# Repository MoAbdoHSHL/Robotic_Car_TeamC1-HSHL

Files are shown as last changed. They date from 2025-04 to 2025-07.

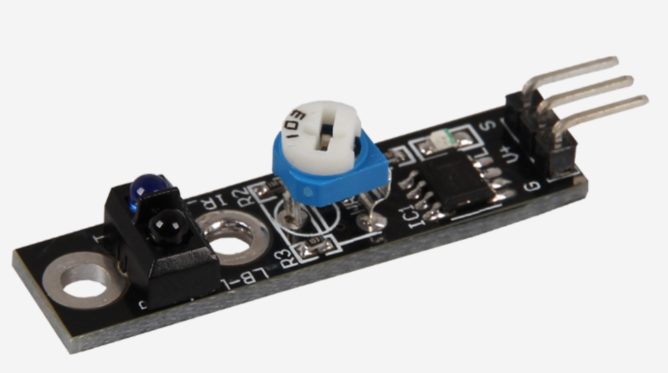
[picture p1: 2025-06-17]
Task-4/Components/IR Sensor.png

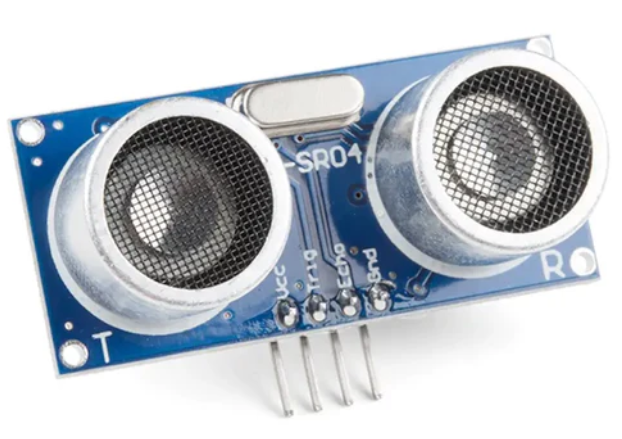
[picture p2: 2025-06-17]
Task-4/Components/Ultrasonic Sensor.png

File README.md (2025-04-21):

# Arduino Autonomous Vehicle 🚗🤖

Front_View_Car

## 🎯 Project Goal

Develop an autonomous vehicle capable of navigating a track **without human control**, using:

- **Line detection** for navigation
- **Obstacle detection and avoidance**
- **Color-based object identification**
   Ex: (to decide route or remove obstacles)
- **Speed optimization** for smooth operation
- **Multiple routing scenarios**:
  - Oval track
  - Figure-eight track
  - Parking maneuvers

## 👥 Team Members
- Mohamed Abdo
- Md Ruhul Kuddus Saleh
- Md Rahman
- Aamir Ejaz

## Initial_Simulation:
https://www.tinkercad.com/things/dzwxTrQqEL3-swanky-snaget/editel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

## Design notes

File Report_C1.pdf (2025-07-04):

# Autonomous Line-Following Vehicle with Integrated Obstacle and Color Detection System

Mohamed Abdo∗

, Muhammad Aamir Ejaz Ejaz∗

,Md Ruhul Kuddus Saleh∗

, Md Mostafizur Rahman∗
∗Systems Engineering and Prototyping, BSc Electronic Engineering Hochschule Hamm-Lippstadt, Lippstadt, Germany {mohamed-sayed-mohamed.abdo, muhammad-aamir.ejaz-ejaz, md-ruhul-kuddus.saleh, md-mostafizur.rahman}@stud.hshl.de

Abstract—In this study, our team’s line-following vehicle prototype is shown. The robot can follow designated routes, recognize and detect obstacles, identify their color, and react appropriately based on that color. The project’s objectives, hardware design, electronic components, and programming strategies are all examined in this article in order to accomplish the intended functionality. Additionally, it displays the tasks finished, tests conducted, and experiments conducted during the semester in order to evaluate and validate the efficacy of the system.
Index Terms—Line follower robot,
I. INTRODUCTION

This project presents an autonomous line-following vehicle capable of obstacle detection and color-based decision-making. Using an Arduino UNO R4, IR sensors, ultrasonic sensors, and a TCS3200 color sensor, the vehicle follows a black line and reacts to obstacles intelligently. It overtakes red objects, pushes green, and performs park maneuver if the object color is unknown. A servo-mounted ultrasonic sensor enhances obstacle scanning, while a voltage monitoring system adjusts speed for optimal performance. This project integrates embedded systems, sensor fusion, and robotics control, offering a practical model for intelligent navigation.

II. SYSTEM DESIGN AND ENGINEERING

The system design of the autonomous vehicle integrates hardware components and embedded logic to achieve efficient and adaptive navigation. The core controller, an Arduino UNO R4, manages sensor data processing and motor control. Two infrared sensors are positioned to detect the black line path, enabling continuous line-following behavior.
For obstacle detection, an ultrasonic sensor is mounted on a servo motor, allowing dynamic scanning of the surroundings. This rotating sensor increases detection accuracy and helps in planning overtaking maneuvers. A TCS3200 color sensor is used to identify the color of the obstacle, determining how the vehicle should react: when the car detects red, it starts to overtake, when it detects green, it pushes, and when it detects an unidentified object, it parks.
Motor control is achieved through an L298N motor driver, which provides bidirectional movement and turning. A voltage monitoring system adjusts the car’s speed based on battery levels to maintain consistent performance. The coordination between sensors, actuators, and programmed logic forms a robust embedded control system for real-time decision-making.

III. PROTOTYPING AND DESIGN

A. Electronic Components
The vehicle’s control system is centered around an Arduino UNO R4, which manages inputs from sensors and outputs to motors. Two infrared (IR) sensors are mounted at the front underside of the chassis to track the black line on the ground. An ultrasonic sensor, mounted on a vertical plate, provides distance measurements for obstacle detection. The TCS3200 color sensor is positioned close to the ground to accurately detect object color. An L298N motor driver is used for bidirectional control of the DC motors, and a voltage divider circuit is included to monitor battery levels in real-time.
B. Virtual and Physical Prototypes
The design process began with virtual prototyping using SolidWorks to visualize the mechanical structure and component placement. The virtual prototype allowed optimization of sensor angles, wheel spacing, and clearances before committing to physical assembly. After finalizing the CAD model, the physical prototype was built using a two-level chassis made from lightweight materials to separate the sensor and control layers. Multiple iterations were conducted to test wiring layout, sensor performance, and motor response.
C. Hardware Assembly
The hardware was mounted as per the CAD model. The ultrasonic sensor is fixed on a frontal panel with symmetrical alignment to maximize forward detection range. Below the base plate, the IR sensors are angled slightly downward for optimal ground visibility. The servo motor controlling the ultrasonic scanner is centrally positioned to sweep the surroundings effectively. All electronic components, including the Arduino board, motor driver, and battery pack, are mounted securely to minimize vibrations and maintain system stability during motion. The structured layout ensures efficient wiring, accessibility for maintenance, and protection of components during operation.

IV. SYSML DIAGRAMS

A. Requirement Diagram
The criteria for the autonomous vehicle system are shown in Figure 1 Line-following, dynamic speed control, and color-based obstacle handling are all supported. The Unknown colors cause the car to park, green starts a push action, and red starts an overtaking maneuver. Figure 1 displays the requirements for the autonomous car system. Line-following, dynamic speed control, and color-based obstacle handling are all supported by the system. Green barriers are pushed aside, red starts a detour, and unidentified hues result in a parking maneuver. The sensor-driven, modular architecture of the design guarantees dependable and secure navigation.

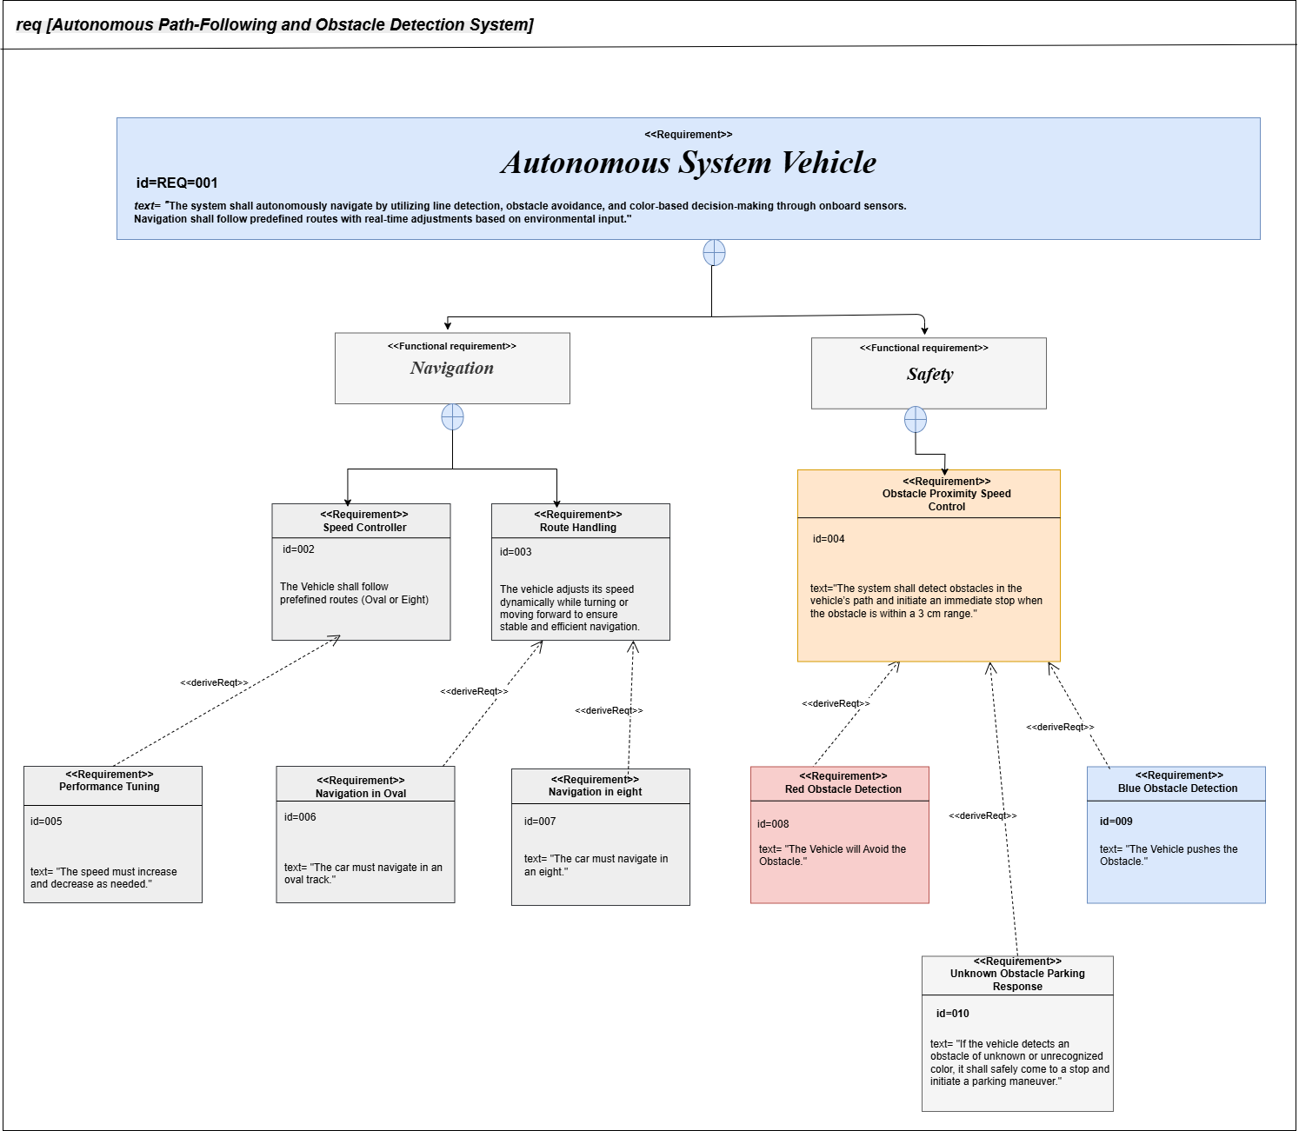
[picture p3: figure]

Fig. 1. Requirement Diagram

B. State Machine Diagram

A state machine model is used in Figure. 2 to depict the control logic of the autonomous vehicle in order to support this behavior. The system starts in idle mode and then switches to line-following navigation. The car branches its behavior based on color input when it detects obstacles: green starts a push action, red starts a detour, and unknown colors force the car to halt and park. When a task is finished or unrecoverable situations are encountered, the system enters a standstill state. In order to preserve operational safety, emergency transitions also manage situations like line loss.

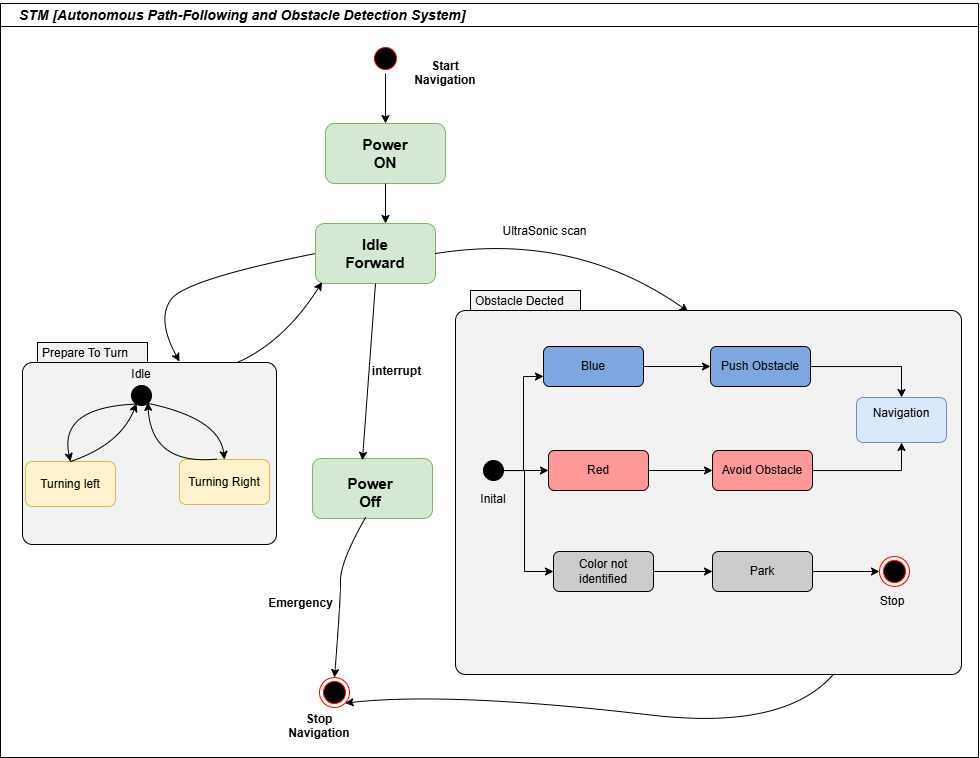
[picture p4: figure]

Fig. 2. State Machine Diagram

C. Activity Diagram
The activity diagram in Figure. 3shows the autonomous vehicle’s operating flow in accordance with the state machine logic. By modifying its motion in response to line detection, the system initiates autonomous navigation. It continuously recognizes and assesses the color of obstacles it detects as it moves forward. Unknown colors cause the car to stop and park, green starts a push maneuver, and red starts a detour that is followed by a return to the main path. Until the route is successfully finished or the system is manually stopped, this process keeps on.

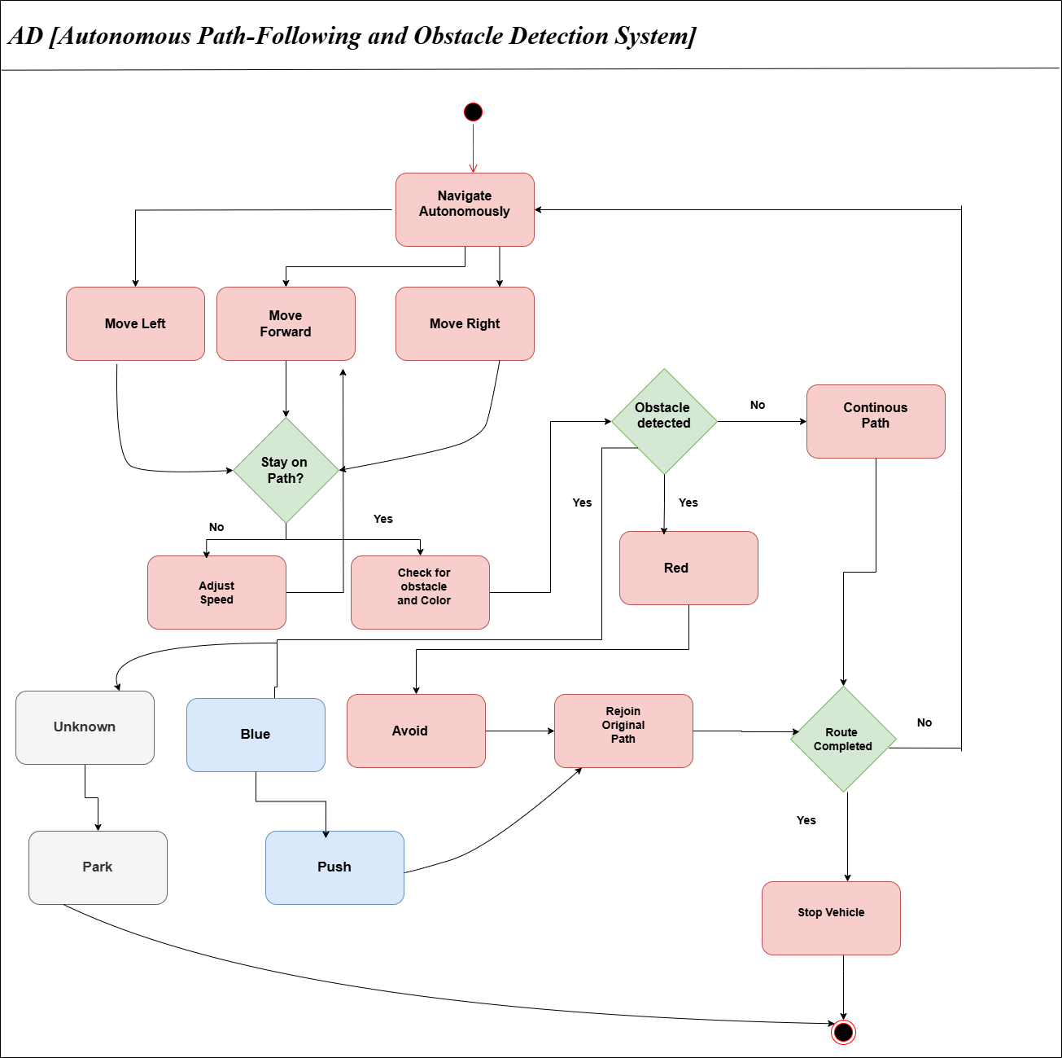
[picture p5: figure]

Fig. 3. Activity Diagram

D. Use Case Diagram
The use case diagram Figure. 4 depicts the main characteristics of the Autonomous Path-Following and Obstacle Detection System. As the primary external actors, the team members engage with the system by turning it on and off using the switch on/off feature. The technology automatically navigates once it is turned on, detecting lines, obstacles, and regulating speed. Using line-following logic, the navigation process facilitates directional decisions like turning left or right. The system uses obstacle detection to make color-based decisions: unknown colors, as specified by the modified system behavior, force the vehicle to stop and park; green obstacles commence a push maneuver; and red obstacles start an avoidance or detour sequence. Furthermore, under the speed-regulated navigation mode, the system can follow predefined path patterns like oval and figure-eight routes.
E. Sequence Diagram
The sequence diagram Figure.5 shows how the various parts of the system interact during autonomous navigation. Line detection and sensor activation are started when the user turns on the system. The car continuously looks for obstructions as it travels forward. Green obstacles are pushed aside, red obstacles cause an overtaking action, and unknown colors cause the system to halt and park. The system employs the color sensor to classify obstacles when it detects them. In

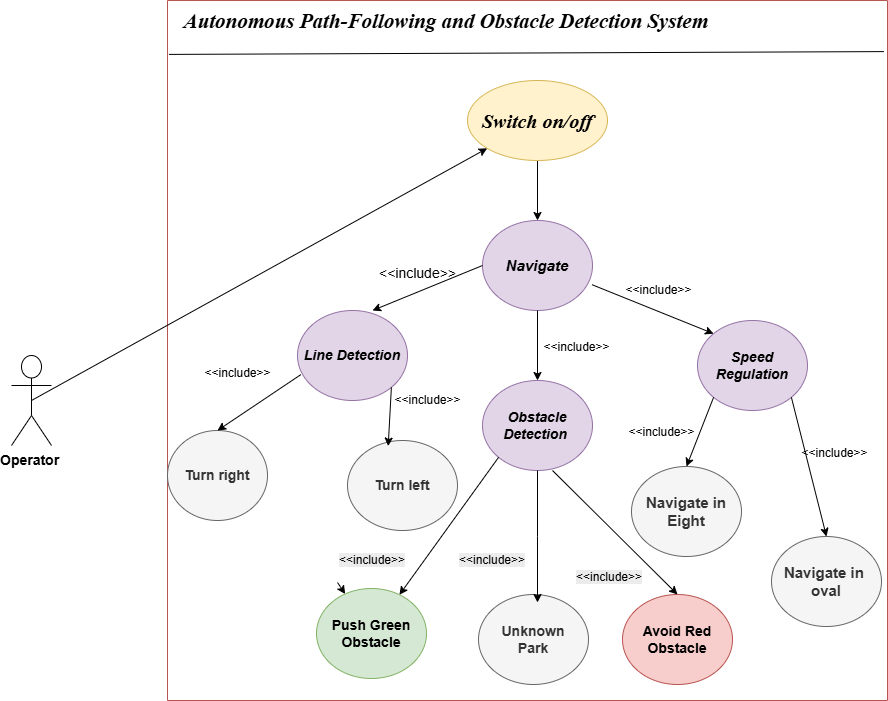
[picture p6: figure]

Fig. 4. Use Case Diagram

the meantime, motor control uses input from the servo’s area scan to dynamically modify speed and direction. Smooth, autonomous navigation is made possible by this time-sequenced interaction, which guarantees real-time decision-making.

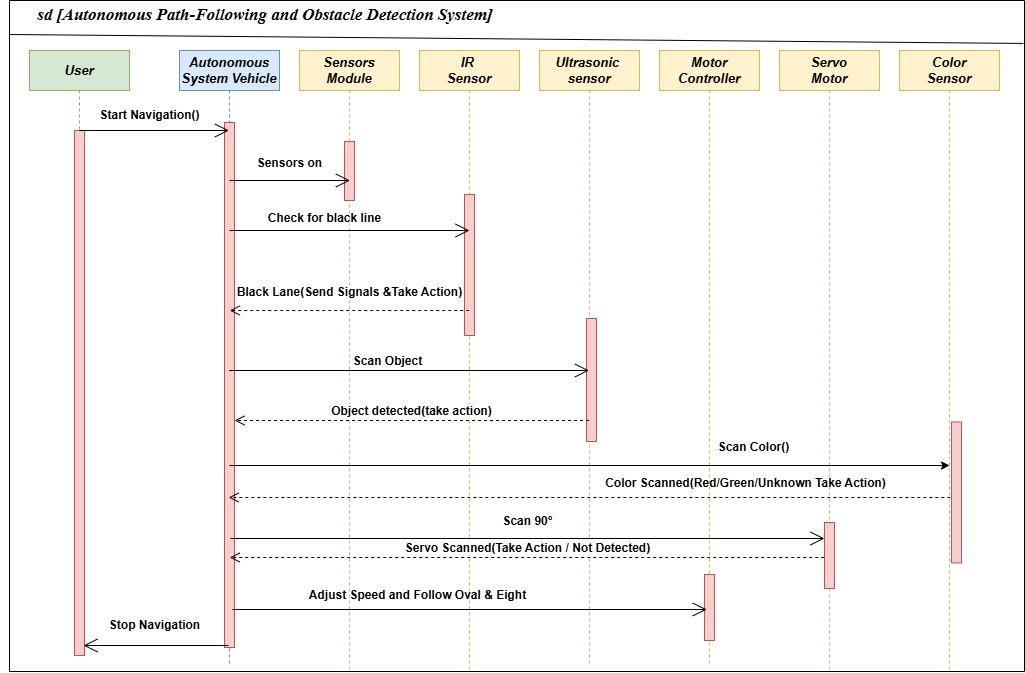
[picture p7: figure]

Fig. 5. Sequence Diagram

V. STRUCTURE DIAGRAMS
The autonomous vehicle system’s static architecture is specified via structure diagrams. They show how hardware and software components are arranged, relate to one another, and work together to support navigation, obstacle detection, and decision-making features.
A. Block Definition Diagram
Moving onto the structure part of the SysML,we start with the Block Definition Diagram (BDD). The BDD in Figure. 6 is used to model the structural composition of the autonomous vehicle system, emphasizing how the system is organized and broken down into functional parts. It demonstrates how the two main subsystems safety and navigation are further broken down into essential elements like line detection, obstacle avoidance, and route selection. Because these functional blocks are linked to hardware elements like motors, sensors, and the Arduino UNO, they show how software logic is translated onto the physical architecture. The way that different components work together to enable the vehicle’s autonomous behavior is clearly understood thanks to this structural representation.

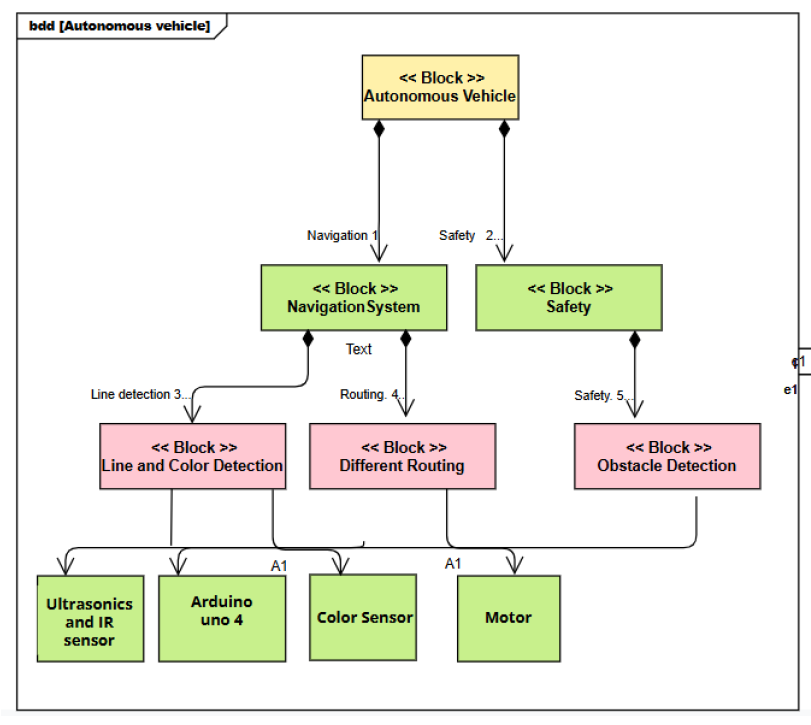
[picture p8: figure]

Fig. 6. Block Definition Diagram

B. Package Diagram
The autonomous vehicle system’s modular design is depicted in the package diagram Figure. 7 . It divides related tasks into logical subsystems, including obstacle handling, color detection, and navigation. Sensors, actuators, and system logic are all coordinated by the Arduino UNO, which serves as the main controller. All active components are supported by the power supply, guaranteeing continuous functioning. The control, sensor, and actuation layers are neatly divided in this system.
C. Internal Body Diagram
The autonomous vehicle’s internal organization and communication flow are depicted in the internal block diagram Figure. 8 . The Line and Color Detection device processes sensor data from infrared, ultrasonic, and color sensors and sends pertinent signals to the Arduino UNO. Coordinated tire movement is the consequence of the Arduino controlling the motor depending on the processed inputs. This configuration demonstrates how perception, control, and actuation elements can be integrated.
D. Parametric Diagram
The autonomous vehicle system’s dependencies and limitations are depicted in the parametric diagram Figure. 9 It demonstrates how important features like line following and obstacle identification are influenced by sensor inputs and preset factors like track type and obstacle behavior. As the primary controller, the Arduino UNO processes inputs from infrared and ultrasonic sensors and regulates tire movement in response to system circumstances.

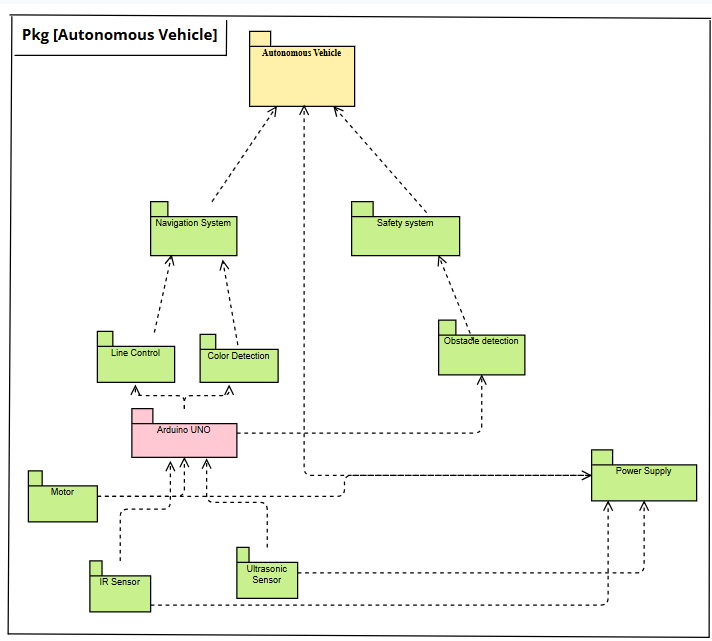
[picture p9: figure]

Fig. 7. Package Diagram

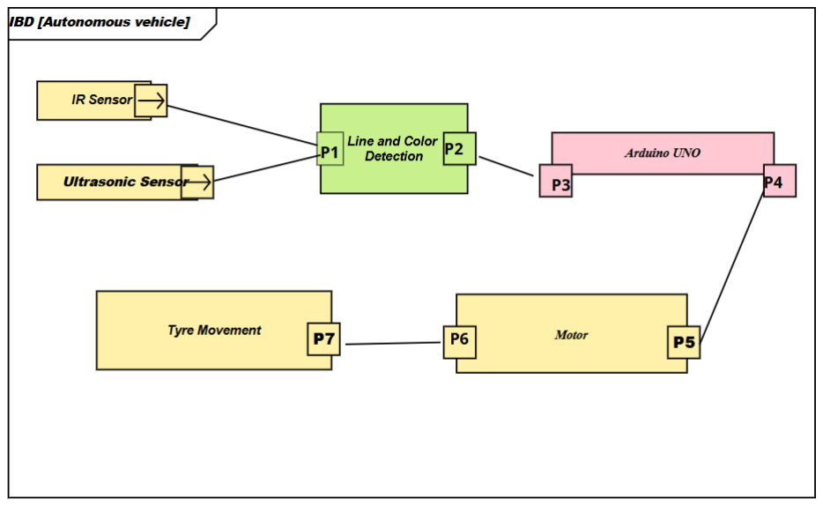
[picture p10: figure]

Fig. 8. Internal Body Diagram

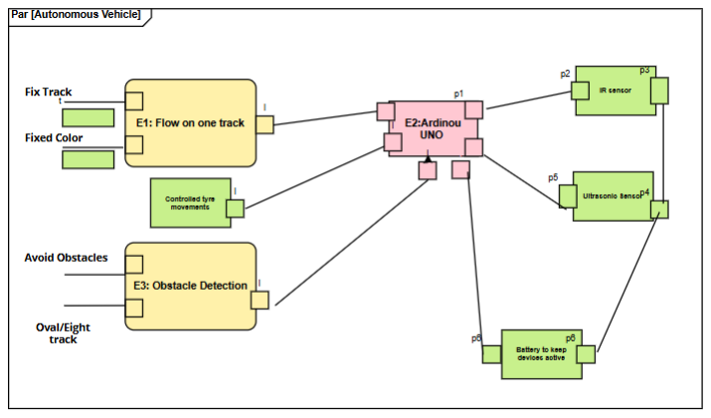
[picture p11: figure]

Fig. 9. Parametric Diagram

VI. AUTONOMOUS NAVIGATION SIMULATION

We ran a number of simulations, starting with the electronic circuitry, to confirm the suggested autonomous car system’s operation prior to its actual deployment. We created and modelled the main electrical circuit using Multisim in order to confirm sensor integration, motor driver behavior, and power distribution.

A. Multisim Simulation

The autonomous vehicle’s circuit diagram is displayed in Figure. 10. An LM7805CT voltage regulator is used to regulate the system’s 11.1 V battery to 5 V so that all of its parts can operate safely. The wheels are driven by two DC motors that are managed by a motor driver. Two infrared sensor pairs each comprising an IR LED and phototransistor as well as pull-up and current limiting resistors for signal stability are used to accomplish line-following. While a color sensor recognizes the colors of objects, an ultrasonic sensor finds impediments. The ultrasonic sensor is rotated for scanning by a servo motor. The circuit has a switch to turn on the system and capacitors to smooth out power.With this configuration, the car can assess its surroundings and decide how to travel in real time.

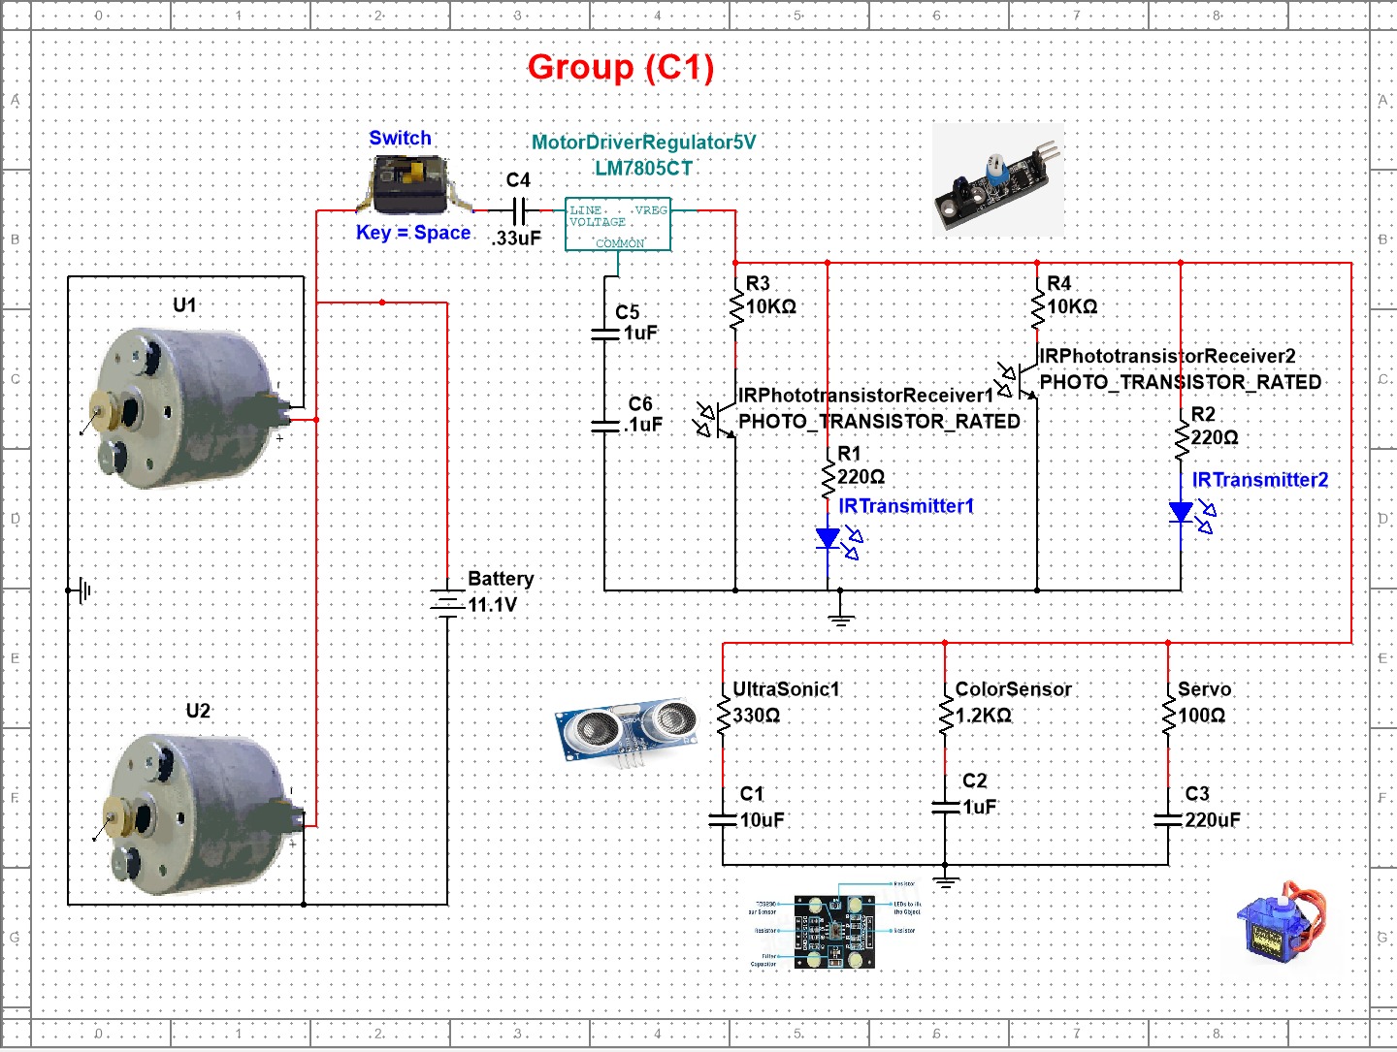
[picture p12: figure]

Fig. 10. Multisim simulation

B. Tinkercad Simulation

Tinkercad, a virtual electronics platform that enables circuit design and testing without actual components, was used to simulate the hardware implementation of the autonomous car system Figure. 11 An H-bridge motor driver is used in the simulation to connect an Arduino UNO microcontroller to two DC motors, enabling directional control. IR sensors are placed for white line tracking, and an ultrasonic sensor (HC-SR04) is employed for obstacle detection. A 9V battery powers the system, and a breadboard is used in the setup to control connections and power distribution. Before the system is physically deployed, the simulation verifies its viability in the real world by validating motor control logic, sensor responses, and navigation behavior.

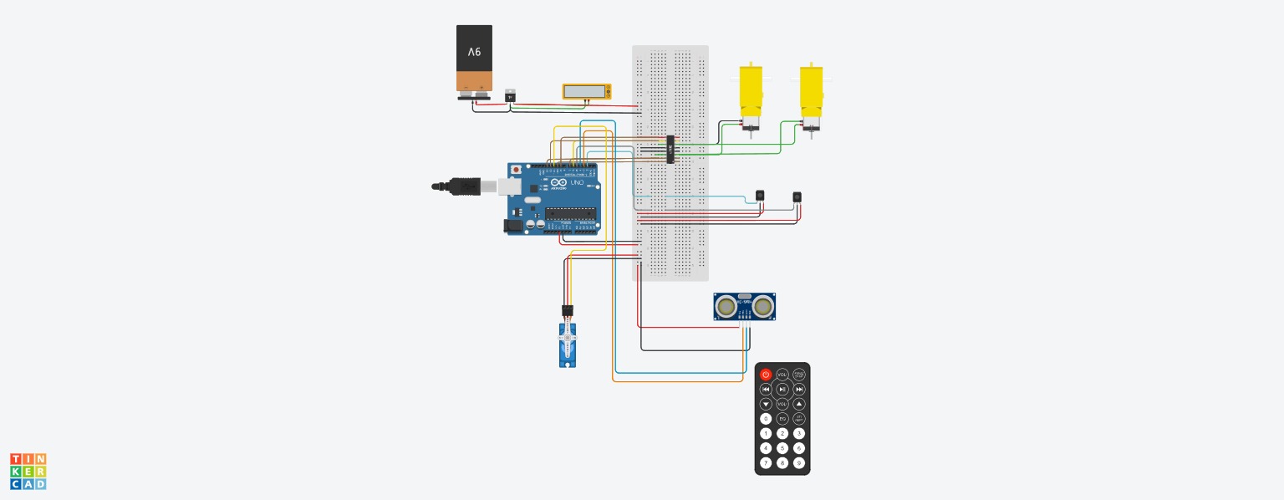
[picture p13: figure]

Fig. 11. Tinkercad simulation

C. Schematic View
A detailed schematic diagram Figure. 12 was created to depict the real hardware wiring of the autonomous car system after the Tinkercad simulation. All necessary electrical connections and component interconnections are depicted in the schematic. The central component is the Arduino UNO microcontroller (U1), which communicates with a servo motor (SERVO1) for scanning, an ultrasonic sensor (DIST1) for obstacle detection, and an H-Bridge motor driver (U5) for bidirectional motor control. A voltage regulator (U4) controls a 9V battery to provide steady 5V output. The direction movement is made possible by the motor driver, which controls the two DC motors (M1 and M2). For improved sensing and signal dependability, further modules are integrated, such as resistors and color sensors (U2, U3). Before the circuit is physically assembled, this schematic guarantees a precise implementation.

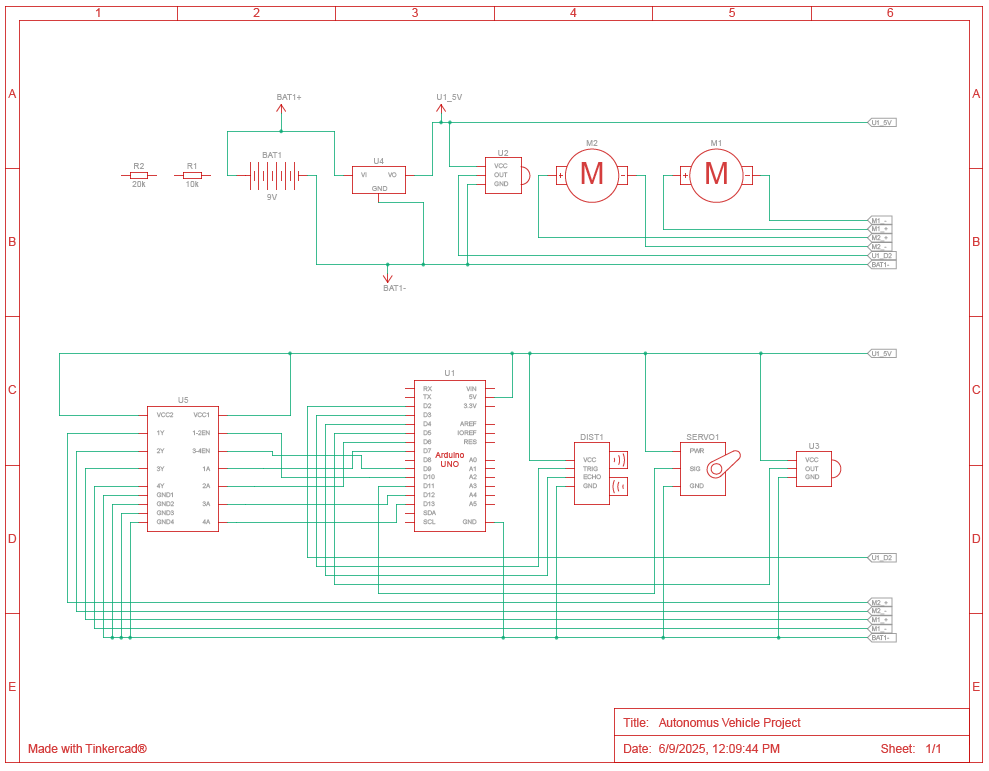
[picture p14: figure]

Fig. 12. Schematic View

VII. UPPAAL-BASED BEHAVIORAL MODELING AND SIMULATION
We used UPPAAL, a real-time system modeling tool for validating and verifying timed automata, to model the vehicle’s decision-making logic in order to guarantee dependable and secure behavior in autonomous navigation. The model is made up of multiple interacting timed automata, each of which is in charge of a distinct functional component of the behavior of the autonomous car.
A. Main Navigation Controller
The primary controller automaton in charge of guiding the vehicle’s fundamental movement behaviors is depicted in the Figure. 13. After the Move trigger, it moves from an initial SwitchOn state to MoveForward. The automata switches between states like TurnLeft, TurnRight, Stop, and obstaclerelated handling states like ColourCheck, OvertakeObstacle, and MoveTheObstacle in response to different sensor inputs. To ensure context-aware reactions, events like RedObstacle, GreenObstacle, or UnknownObstacle! initiate each transition.

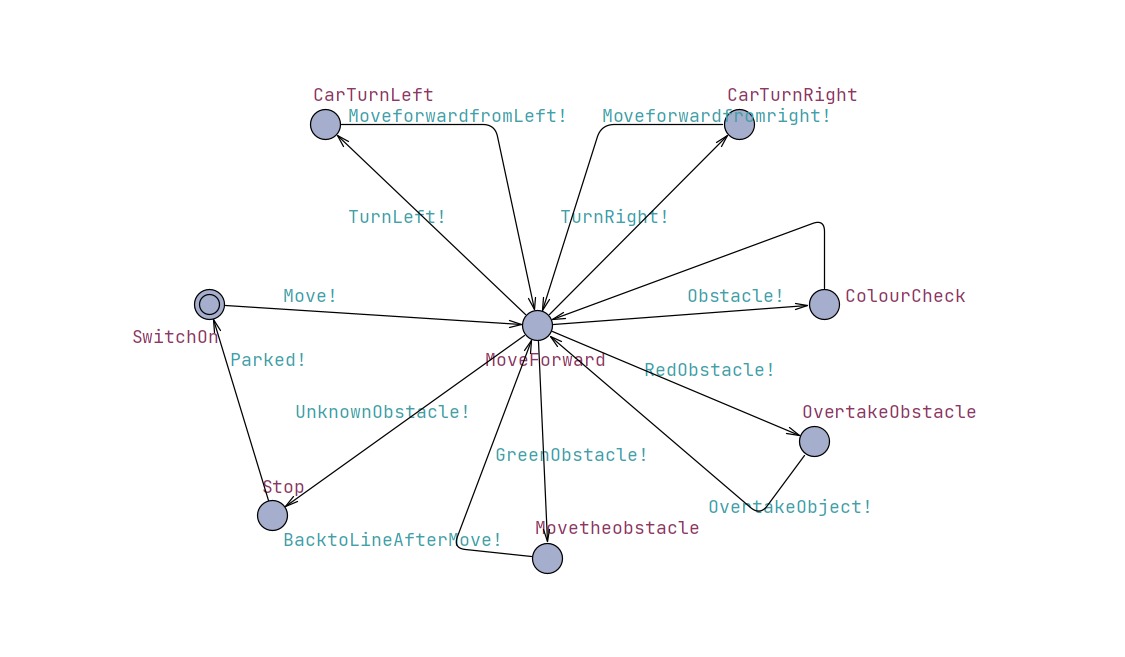
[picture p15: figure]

Fig. 13. Main Navigation Controller

B. Obstacle Detection and Response Logic

When the system identifies a potential obstacle, it switches from the Obstacle free state to the Measuring Distance state (Move?) Figure. 14. It transitions to the Obstacle Detected state and then to Colour Check to determine the object’s color if an obstacle is verified (Obstacle?). The system determines what to do next, If the obstacle is red, the vehicle initiates an overtaking maneuver. If the obstacle is green, it performs a pushing action. For unknown color obstacles, the vehicle decides to park aside. The system reverts to the Obstacle free state and resumes regular function once the impediment has been effectively avoided or eliminated.

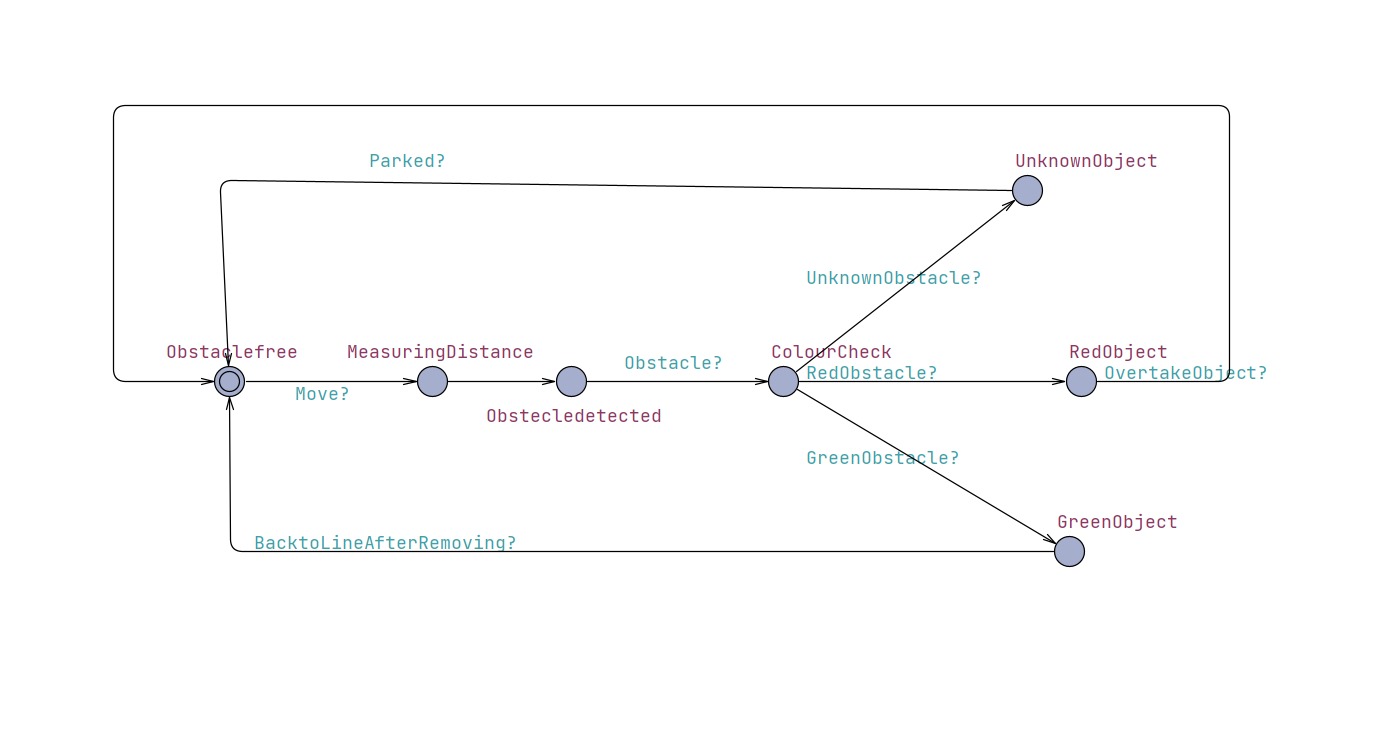
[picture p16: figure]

Fig. 14. Obstacle Detection and Response Logic

C. Left Side Behavior

The behavior of the left-side IR sensor is modeled by this automata. When the vehicle is not on line (CarNotOnLine), it turns on, checks the LeftIRon condition, makes a left correction (TurnLeft?) and then switches back to MoveForward Figure. 15.

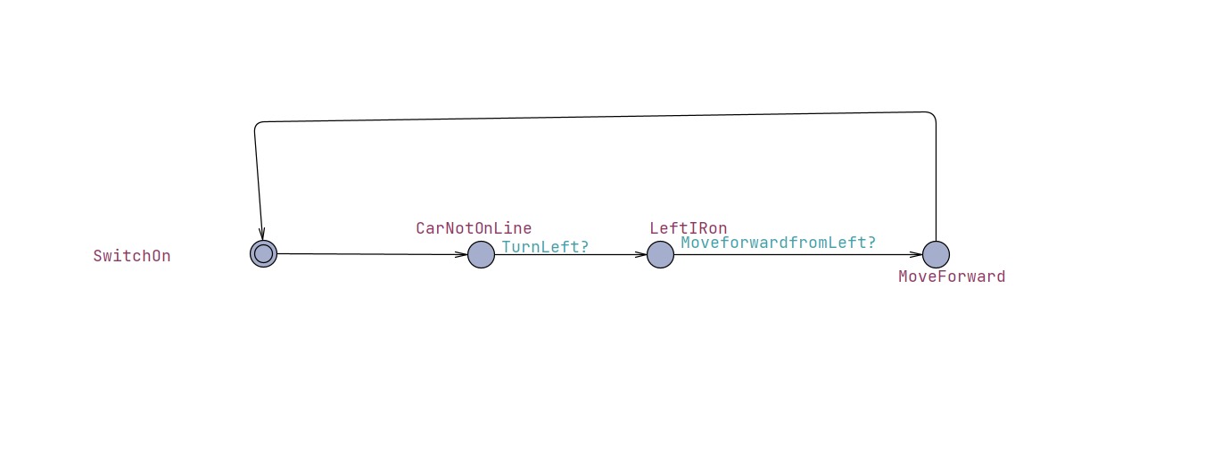
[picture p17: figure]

Fig. 15. Left Side Behavior

D. Right Side Behavior
The opposite of the left IR behavior is this Figure. 16. Before going back to MoveForward, it reacts to CarNotOn-Line, checks the RightIRon signal, and orders a right turn (TurnRight?).

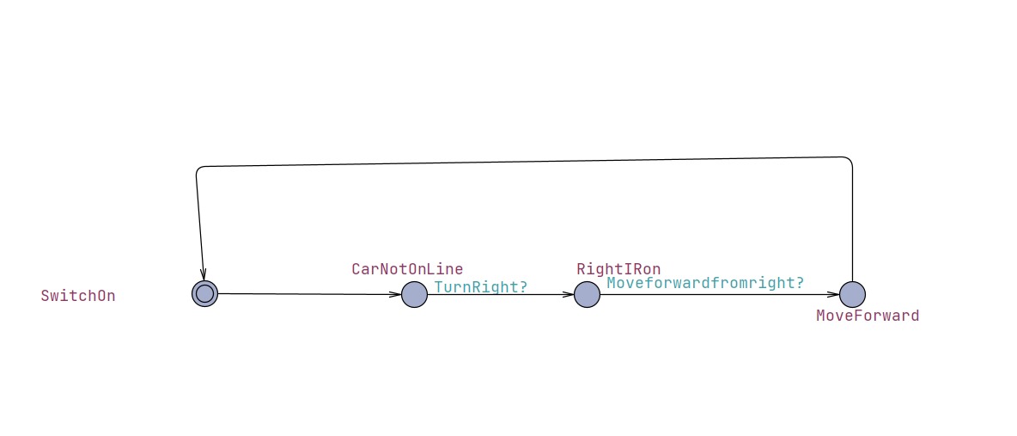
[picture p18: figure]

Fig. 16. Right Side Behavior

VIII. 3-D CAD MODEL OF THE AUTONOMOUS CAR PROTOTYPE

The completed 3D CAD design of the autonomous vehicle created for this project is shown in Figure. 17 Throughout the building process, the CAD model was a vital source of information that guaranteed precise component placement and spatial alignment. Important hardware elements like dualwheel differential drive systems, onboard controller mounts, ultrasonic sensors, and DC motors with encoders are all integrated into the design. Notably, the front panel sensor mount facilitates ambient awareness and obstacle recognition, both of which are critical for autonomous navigation activities. This design is carefully followed in the physical assembly, demonstrating the value of CAD modeling in system integration and iterative prototyping.

IX. ELECTRONICS PARTS USED

An Arduino Uno microcontroller serves as the main component of the autonomous car’s electronics system, interacting with a variety of sensors and actuators. A TCS3200 color sensor for object categorization, an ultrasonic sensor for obstacle detection, and infrared sensors for line following are important parts. For directed scanning, the ultrasonic sensor is rotated by a servo motor. A 7.4 V or 11.1 V LiPo battery powers the L298N twin H-bridge motor driver, which controls the motors. Sensitive components receive a steady 5 V power supply thanks to a voltage regulator. A breadboard and jumper

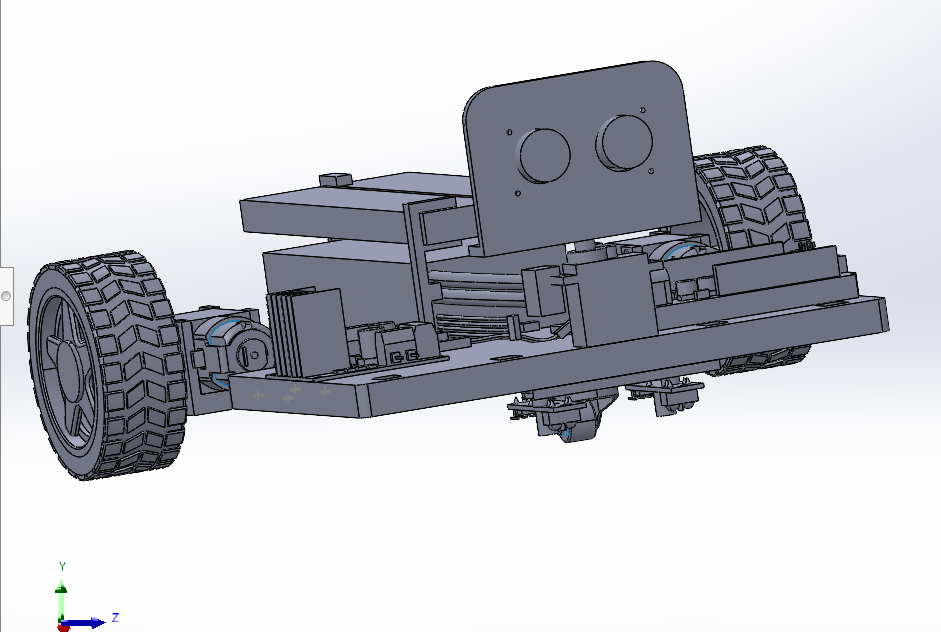
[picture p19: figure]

Fig. 17. 3-D CAD Model

wires link all the components, allowing for modular and test-friendly assembly.

A. Arduino Uno R4
The Arduino Uno R4 Figure. 18 serves as its main controller, gathering input from sensors, processing it, and using actuators to initiate the required steps to allow movement. It is based on the Atmega328 microcontroller, which has an 8-bit RISC processor core and is a member of the Atmel family. As seen in Figure 16, the board has six analog input pins and fourteen digital GPIO pins. It communicates with a PC over a USB interface.The Arduino Uno is notable for its Atmega328P microcontroller, which has six analog input pins, 14 digital GPIO ports, and an 8-bit RISC CPU core. Because of these features, the Arduino Uno can effectively manage sensor inputs and control actuators, which makes it an essential part of the prototype’s operation. [1]

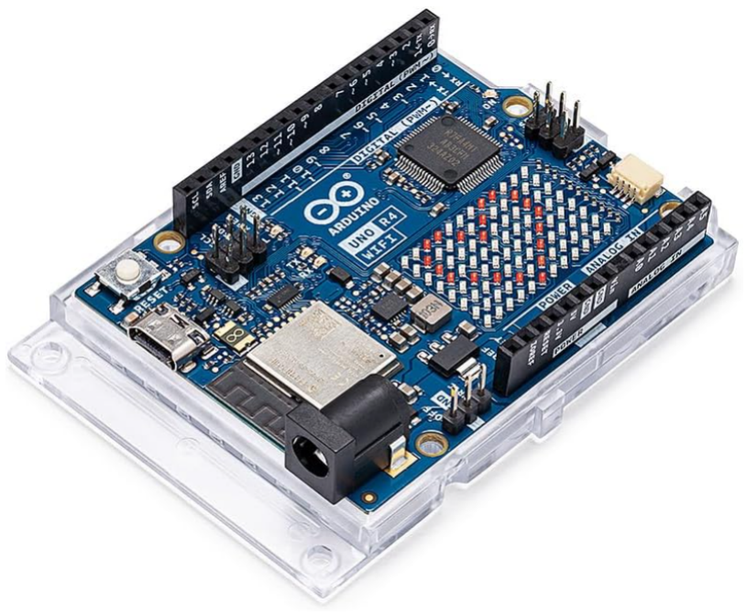
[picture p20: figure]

Fig. 18. Arduino Uno R4

B. Ultrasonic Sensor
The Ultrasonic sensors Figure. 19 with a resolution of about 3 mm via ultrasonic signaling, this module is ideal for measuring distances ranging from 2 cm to 3 meters. The sensor starts measuring distance when a falling edge signal is applied to the trigger input. The distance measurement is then output as a PWM TTL signal from the echo pin. Applications including obstacle detection, distance measuring, liquid level monitoring, and other industrial uses are where the ultrasonic distance sensor excels. When activated, the ultrasonic transducer produces a 200 s burst of ultrasonic waves at a frequency of 40 kHz, which produces 8 signal cycles at that time. A 10 s high-level pulse applied to the trigger input pin causes this emission. The echo output pin then swings high after this. The echo pin is pulled low when the microphone receives the reflected ultrasonic wave.The ultrasonic wave’s round-trip travel time from the transducer to the reflecting item and back is represented by the amount of time the echo pin stays high. It is possible to compute the distance to the object (as half the total traveled distance) by measuring this duration and assuming that sound travels at a constant speed in air. [2]


Fig. 19. Ultrasonic Sensor

C. IR Sensor
We make use of photodiodes, which are infrared (IR) transmitters and receivers Figure. 20 The photodiode serves as the receiver, identifying the reflected infrared signals and transmitting the relevant data to the microcontroller. The IR transmitter is an LED that emits infrared light. A detectable voltage shift occurs when the infrared light strikes a white surface because it is reflected back and picked up by the photodiode. On the other hand, when infrared light hits a black surface, it is absorbed instead of reflected, and the photodiode doesn’t get any signal [3].
D. Color Sensor
An array of photodiodes filtered for red, green, blue, and clear (unfiltered) light is how the TCS3200 color sensor works Figure. 21. The 4x4 matrix arrangement of these photodiodes enables precise measurement of light intensity throughout the visible spectrum. A current-to-frequency converter built inside the sensor produces a square wave signal whose frequency is proportional to the color’s intensity. The sensor can separate and measure the intensity of red, green, or blue light separately since the selection of particular color channels is digitally

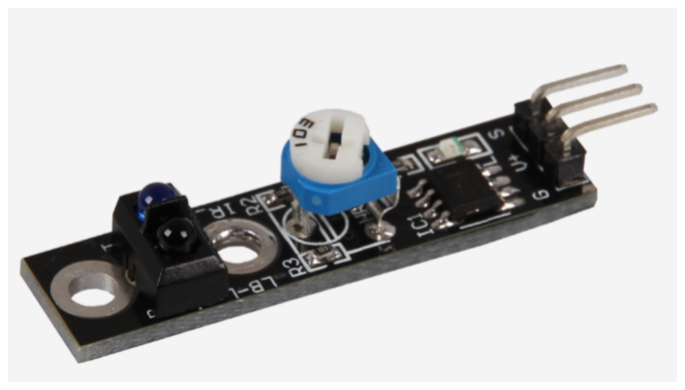
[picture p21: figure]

Fig. 20. IR Sensor

controlled. Depending on the color composition of the light, the matching photodiodes produce current when it reflects off a surface and enters the sensor. After that, this current is transformed into a frequency signal that a microcontroller can read and process to ascertain the surface’s hue. Because of this feature, the TCS3200 can be used in a number of applications, such as embedded robotics, industrial sorting systems, and color identification [4].

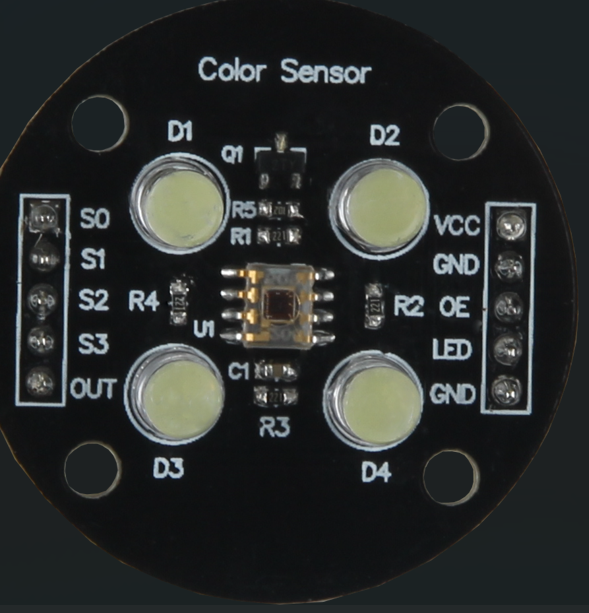
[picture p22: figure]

Fig. 21. Color Sensor

E. Motor Controller
The L298N is a dual-channel H-bridge motor driver that can provide both speed and direction control for two DC motors or one stepper motor Figure. 22. It can withstand peak currents of up to 2 A per channel and take motor supply voltages ranging from 5 V to 35 V (with an absolute maximum of 46 V).Two enable pins (ENA and ENB) receive PWM signals to control speed, and two logic inputs (IN1/IN2 for Motor A and IN3/IN4 for Motor B) control each H-bridge section by determining motor direction. If the input voltage is 12 V or less, the module’s onboard 78M05 linear regulator, which supplies a 5 V logic supply, can also power an external microcontroller.Integrated flyback diodes to guard against inductive voltage spikes and thermal shutdown to stop overheating are examples of protection features. For robotics, industrial actuation, and applications that require bidirectional motor control with changing speed, this makes the L298N module ideal [5].
F. Lippo Battery
A Conrad 7.4V 3000mAh 20C Eco-Line LiPo battery, illustrated in Figure. 23 , was used to supply power to the L298N motor driver. According to the manufacturer, the battery weighs approximately 210 grams [6].

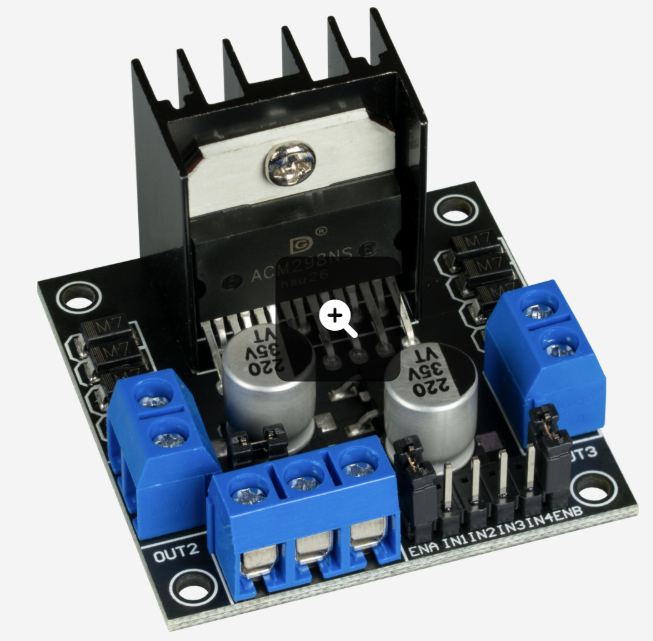
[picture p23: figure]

Fig. 22. Motor Controller

Fig. 23. Lippo Battery

X. SOFTWARE IMPLEMENTATION
A. Initialization of Sensors and Actuators
To get the system ready for use, all the sensors and actuators are initialized in the Setup function of the Arduino code. This entails specifying the pin modes for servo motors, motors, color sensors, ultrasonic sensors, and infrared (IR) sensors. Depending on its purpose, each component is set up as either an input or an output. Additionally, serial communication is set up for monitoring and debugging. Pins for sensors were defined and initialized in the ‘setup()‘ function. Below is a snippet:

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

/ / IR s e n s o r s
pinMode ( R S , INPUT ) ;
/ / R i g h t IR s e n s o r pinMode ( L S , INPUT ) ;
/ / L e f t IR s e n s o r

/ / Motor c o n t r o l p i n s pinMode ( enA , OUTPUT ) ; pinMode ( in1 , OUTPUT ) ; pinMode ( in2 , OUTPUT ) ; pinMode ( in3 , OUTPUT ) ; pinMode ( in4 , OUTPUT ) ; pinMode ( enB , OUTPUT ) ;

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

/ / Color s e n s o r
pinMode ( S0 , OUTPUT ) ;
pinMode ( S1 , OUTPUT ) ;

pinMode ( S2 , OUTPUT ) ;
pinMode ( S3 , OUTPUT ) ;
pinMode ( co lo rO ut , INPUT ) ; d i g i t a l W r i t e ( S0 , HIGH ) ;
d i g i t a l W r i t e ( S1 , LOW) ;

/ / Servo motor
s c a n S e r v o . a t t a c h ( s e r v o P i n ) ; s c a n S e r v o . w r i t e ( 5 0 ) ;
/ / S t a r t a t c e n t e r p o s i t i o n
d e l a y ( 3 0 0 ) ;
}
B. Movement Control Algorithms
Both programmed decision-making logic and sensor feedback regulate the autonomous vehicle’s movement. A black line on the track is followed by infrared (IR) sensors. In order to maintain alignment, the algorithm continuously examines the values from the left and right infrared sensors. If both detect the line, the robot advances; if only one does, it turns in that direction. An ultrasonic sensor tracks the separation between barriers.The car pauses and activates color detection when it detects an object within a predetermined threshold. Different operations are carried out based on the detected color: blue starts a parking routine by reversing, turning, and halting; green commences a forward-and-reverse bypass; and red initiates a right-side diversion and rejoining of the line. PWM signals are used to dynamically modify motor speed, ensuring smooth turning and obstacle-handling. The robot can move in both reactive and adaptable ways on its own thanks to these control systems.
C. Behavioral Decision Logic
The way the car changes states in response to sensor input is controlled by the behavioral decision logic. Under typical circumstances, the car uses infrared sensors to follow the line. The car shifts into ”approach” mode, cautiously approaching an obstruction when the ultrasonic sensor detects it within a predetermined distance. The system stops when it reaches a closer threshold and classifies the object using the color sensor.Depending on the color it senses, the robot does a certain action: blue parks the car and stops its motion, green is ignored after a brief sidestep, and red initiates a diversion. If the line is lost at any of these stages, the system resets and starts an emergency pause. This decision logic ensures that the robot can adapt its actions dynamically to changes in the surroundings.

XI. FINAL AUTONOMOUS CAR PROTOTYPE
The autonomous car’s final prototype, depicted in Figure. 24 combines a number of sensors and electronic parts on a robotic platform with two wheels. The system is constructed on a wooden chassis and contains two DC motors that power the differential drive. A geared motor mount connects each motor to the wheels. By monitoring the surroundings, an ultrasonic sensor mounted on a servo motor at the front allows for dynamic obstacle detection. A TCS3200 color sensor is mounted directly beneath it to identify and categorize the colors of objects along the route. Infrared sensors positioned beneath the chassis and oriented to track black-and-white path transitions are used to implement line-following capabilities. Component integration and wiring are made easier by a single breadboard, which also makes connection testing and modification simple. An Arduino Uno manages the control logic, processing sensor inputs and adjusting actuators as necessary. The IR modules, ultrasonic sensor, color sensor, and motor driver (L298N), which is powered by a 7.4V 3000 mAh LiPo battery installed on the chassis, are among the several sensors that are connected via the wire. The arrangement is nonetheless modular and test-friendly, providing flexibility for upcoming enhancements or debugging even though the wiring is complicated due to the large number of interconnected components. Real-time experimentation and formal verification using UPPAAL models were used to validate this entire hardware system.

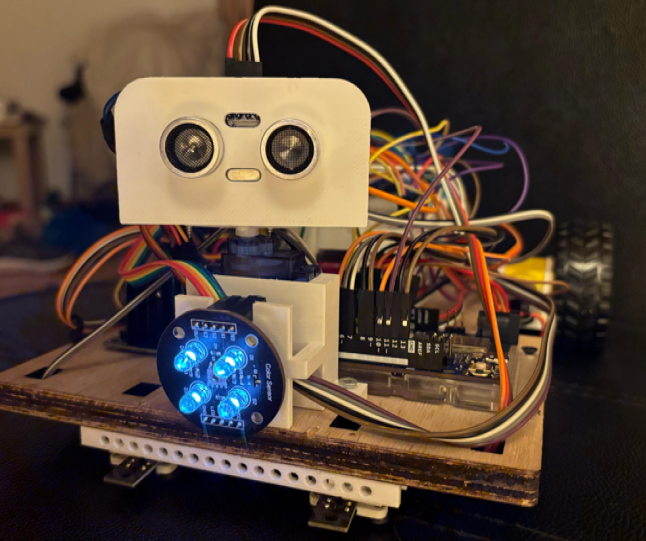
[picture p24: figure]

Fig. 24. Final Prototype

XII. GIT USAGE AND COLLABORATION

Everyone in the team put in equal effort and worked together to complete this project successfully. To guarantee an effective workflow and balanced accountability, tasks were discussed and assigned at the start of the project according to each person’s interests and strengths. Mohamed Abdo concentrated on lane-following programming, soldering, and designing mechanical components. MD Ruhul helped with UPPAAL modeling, 3D printing, and sensor mount design. MD Rahman worked on simulations of voltage regulation, the IR system, and the hardware integration involved. Through documentation and SysML diagrams Muhammad Aamir Ejaz Ejaz made a contribution. To guarantee consistent progress and quality throughout the project, we examined each other’s work, stayed in close contact, and offered mutual assistance. To create a more streamlined and dependable version of the entire system code, we all worked closely together in the last stage to test, debug, and merge our unique contributions.

Team Member | Number of Commits
Mohamed Abdo | 35
Md Ruhul Kuddus Saleh | 24
M Aamir Ejaz Ejaz | 13
Md Mostafizur Rahman | 16
Total | 88
TABLE I
GITHUB COMMITS BY TEAM MEMBERS

XIII. CONCLUSION AND FUTURE WORK

We successfully created an autonomous vehicle in this project that can identify the color of objects, follow lanes, and make decisions based on context. In addition to responding appropriately to recognized barriers based on their color starting an overtaking movement for red obstacles, pushing green objects, and parking aside for unknown colors the automobile consistently recognizes lane borders. These characteristics show how sensor inputs, real-time control logic, and fundamental autonomy can be integrated functionally. By switching from simple microcontroller platforms to more sophisticated hardware, such the Raspberry Pi, we hope to improve the system in subsequent work. This will allow for more processing power, adaptability, and the incorporation of machine learning models. In order to bring the system closer to real-world deployment standards, we also intend to add more professional-grade functionality and enhance the software architecture for improved scalability.

XIV. LIMITATIONS AND SENSOR CALIBRATION CHALLENGES

A significant problem with the color sensor’s capacity to identify the green spectrum was discovered during testing. In particular, the sensor was unable to identify green because of an inadequate output frequency, which needs to be kept at 100 percent (S0=H, S1=H) for precise detection see Fig
25. The issue most likely stems from power constraints that impact the output frequency scaling of the sensor. Specifically for the green photodiode option (S2=H, S3=H), the system needs an external power supply to guarantee a steady and dependable output frequency for accurate color discrimination. This emphasizes how crucial proper power management and calibration are for applications that rely on sensors.

Fig. 25. Color Table

ACKNOWLEDGMENT
This project was made possible through the invaluable support, resources, and expertise provided by Hamm-Lippstadt University of Applied Sciences. We would like to extend our sincere gratitude to Prof. Dr. Stefan Henkler, Prof. Faezeh Pasandideh, and Mr. G. Wahrmann for their unwavering guidance, commitment, and constructive feedback, which played a crucial role in the continuous improvement of our work.

REFERENCES

[1] “Uno | R3,” | Arduino. | [Online]. | Available:
https://docs.arduino.cc/hardware/uno-rev3/. [Accessed: Jun. 27, 2024].
[2] Joy-IT, “KY-050 ultrasonic distance sensor,” SensorKit. [Online]. Available: https://sensorkit.joy-it.net/en/sensors/ky-050. [Accessed: Jun. 27, 2024]
[3] https://www.irjet.net/archives/V7/i2/IRJET-V7I2379.pdf
[4] “TCS3200 | Programmable | Color | Light-to-Frequency | Converter,”
Texas | Advanced | Optoelectronic | Solutions | (TAOS), | [Online].
Available: https://www.mouser.com/catalog/specsheets/tcs3200-e11.pdf. [Accessed: Jun. 27, 2024]
[5] L298N Dual H-Bridge Motor Driver, Handson Technology. [Online]. Available: https://www.handsontec.com/dataspecs/L298N
[6] “Buy Conrad Energy Scale Model Battery Pack (LIPO) 7.4 V 5500 mAh no. of cells: 2 20 C Softcase XT90,” Conrad Electronic. [Online]. Available: https://www.conrad.com/en/p/conrad-energy-scale-modelbattery-pack-lipo-7-4-v-5500-mah-no-of-cells-2-20-c-softcase-xt90-1344152.html. [Accessed: Jun. 27, 2024]

DECLARATION OF ORIGINALITY

We hereby declare that this report is our own work and that we have acknowledged all sources used.

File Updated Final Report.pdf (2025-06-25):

# Autonomous Line-Following Vehicle with Integrated Obstacle and Color Detection System

Mohamed Abdo∗

, M Aamir Ejaz Ejaz∗

,Md Ruhul Kuddus Saleh∗

, Md Mostafizur Rahman∗
∗Systems Engineering and Prototyping, BSc Electronic Engineering Hochschule Hamm-Lippstadt, Lippstadt, Germany {mohamed-sayed-mohamed.abdo, muhammad-aamir.ejaz-ejaz, md-ruhul-kuddus.saleh, md-mostafizur.rahman}@stud.hshl.de

Abstract—In this study, our team’s line-following vehicle prototype is shown. The robot can follow designated routes, recognize and detect obstacles, identify their color, and react appropriately based on that color. The project’s objectives, hardware design, electronic components, and programming strategies are all examined in this article in order to accomplish the intended functionality. Additionally, it displays the tasks finished, tests conducted, and experiments conducted during the semester in order to evaluate and validate the efficacy of the system.
Index Terms—Line follower robot,
I. INTRODUCTION

This project presents an autonomous line-following vehicle capable of obstacle detection and color-based decision-making. Using an Arduino UNO R4, IR sensors, ultrasonic sensors, and a TCS3200 color sensor, the vehicle follows a black line and reacts to obstacles intelligently. It overtakes red objects, pushes green, and performs park maneuver if the object color is unknown. A servo-mounted ultrasonic sensor enhances obstacle scanning, while a voltage monitoring system adjusts speed for optimal performance. This project integrates embedded systems, sensor fusion, and robotics control, offering a practical model for intelligent navigation.

II. SYSTEM DESIGN AND ENGINEERING

The system design of the autonomous vehicle integrates hardware components and embedded logic to achieve efficient and adaptive navigation. The core controller, an Arduino UNO R4, manages sensor data processing and motor control. Two infrared sensors are positioned to detect the black line path, enabling continuous line-following behavior.
For obstacle detection, an ultrasonic sensor is mounted on a servo motor, allowing dynamic scanning of the surroundings. This rotating sensor increases detection accuracy and helps in planning overtaking maneuvers. A TCS3200 color sensor is used to identify the color of the obstacle, determining how the vehicle should react: when the car detects red, it starts to overtake, when it detects green, it pushes, and when it detects an unidentified object, it parks.
Motor control is achieved through an L298N motor driver, which provides bidirectional movement and turning. A voltage monitoring system adjusts the car’s speed based on battery levels to maintain consistent performance. The coordination between sensors, actuators, and programmed logic forms a robust embedded control system for real-time decision-making.

III. PROTOTYPING AND DESIGN

A. Electronic Components
The vehicle’s control system is centered around an Arduino UNO R4, which manages inputs from sensors and outputs to motors. Two infrared (IR) sensors are mounted at the front underside of the chassis to track the black line on the ground. An ultrasonic sensor, mounted on a vertical plate, provides distance measurements for obstacle detection. The TCS3200 color sensor is positioned close to the ground to accurately detect object color. An L298N motor driver is used for bidirectional control of the DC motors, and a voltage divider circuit is included to monitor battery levels in real-time.
B. Virtual and Physical Prototypes
The design process began with virtual prototyping using SolidWorks to visualize the mechanical structure and component placement. The virtual prototype allowed optimization of sensor angles, wheel spacing, and clearances before committing to physical assembly. After finalizing the CAD model, the physical prototype was built using a two-level chassis made from lightweight materials to separate the sensor and control layers. Multiple iterations were conducted to test wiring layout, sensor performance, and motor response.
C. Hardware Assembly
The hardware was mounted as per the CAD model. The ultrasonic sensor is fixed on a frontal panel with symmetrical alignment to maximize forward detection range. Below the base plate, the IR sensors are angled slightly downward for optimal ground visibility. The servo motor controlling the ultrasonic scanner is centrally positioned to sweep the surroundings effectively. All electronic components, including the Arduino board, motor driver, and battery pack, are mounted securely to minimize vibrations and maintain system stability during motion. The structured layout ensures efficient wiring, accessibility for maintenance, and protection of components during operation.

IV. SYSML DIAGRAMS

A. Requirement Diagram
The criteria for the autonomous vehicle system are shown in Figure 1 Line-following, dynamic speed control, and color-based obstacle handling are all supported. The Unknown colors cause the car to park, green starts a push action, and red starts an overtaking maneuver. Figure 1 displays the requirements for the autonomous car system. Line-following, dynamic speed control, and color-based obstacle handling are all supported by the system. Green barriers are pushed aside, red starts a detour, and unidentified hues result in a parking maneuver. The sensor-driven, modular architecture of the design guarantees dependable and secure navigation.


Fig. 1. Requirement Diagram

B. State Machine Diagram

A state machine model is used in Figure. 2 to depict the control logic of the autonomous vehicle in order to support this behavior. The system starts in idle mode and then switches to line-following navigation. The car branches its behavior based on color input when it detects obstacles: green starts a push action, red starts a detour, and unknown colors force the car to halt and park. When a task is finished or unrecoverable situations are encountered, the system enters a standstill state. In order to preserve operational safety, emergency transitions also manage situations like line loss.


Fig. 2. State Machine Diagram

C. Activity Diagram
The activity diagram in Figure. 3shows the autonomous vehicle’s operating flow in accordance with the state machine logic. By modifying its motion in response to line detection, the system initiates autonomous navigation. It continuously recognizes and assesses the color of obstacles it detects as it moves forward. Unknown colors cause the car to stop and park, green starts a push maneuver, and red starts a detour that is followed by a return to the main path. Until the route is successfully finished or the system is manually stopped, this process keeps on.


Fig. 3. Activity Diagram

D. Use Case Diagram
The use case diagram Figure. 4 depicts the main characteristics of the Autonomous Path-Following and Obstacle Detection System. As the primary external actors, the team members engage with the system by turning it on and off using the switch on/off feature. The technology automatically navigates once it is turned on, detecting lines, obstacles, and regulating speed. Using line-following logic, the navigation process facilitates directional decisions like turning left or right. The system uses obstacle detection to make color-based decisions: unknown colors, as specified by the modified system behavior, force the vehicle to stop and park; green obstacles commence a push maneuver; and red obstacles start an avoidance or detour sequence. Furthermore, under the speed-regulated navigation mode, the system can follow predefined path patterns like oval and figure-eight routes.
E. Sequence Diagram
The sequence diagram Figure.5 shows how the various parts of the system interact during autonomous navigation. Line detection and sensor activation are started when the user turns on the system. The car continuously looks for obstructions as it travels forward. Green obstacles are pushed aside, red obstacles cause an overtaking action, and unknown colors cause the system to halt and park. The system employs the color sensor to classify obstacles when it detects them. In


Fig. 4. Use Case Diagram

the meantime, motor control uses input from the servo’s area scan to dynamically modify speed and direction. Smooth, autonomous navigation is made possible by this time-sequenced interaction, which guarantees real-time decision-making.


Fig. 5. Sequence Diagram

V. STRUCTURE DIAGRAMS
The autonomous vehicle system’s static architecture is specified via structure diagrams. They show how hardware and software components are arranged, relate to one another, and work together to support navigation, obstacle detection, and decision-making features.
A. Block Definition Diagram
Moving onto the structure part of the SysML,we start with the Block Definition Diagram (BDD). The BDD in Figure. 6 is used to model the structural composition of the autonomous vehicle system, emphasizing how the system is organized and broken down into functional parts. It demonstrates how the two main subsystems safety and navigation are further broken down into essential elements like line detection, obstacle avoidance, and route selection. Because these functional blocks are linked to hardware elements like motors, sensors, and the Arduino UNO, they show how software logic is translated onto the physical architecture. The way that different components work together to enable the vehicle’s autonomous behavior is clearly understood thanks to this structural representation.


Fig. 6. Block Definition Diagram

B. Package Diagram
The autonomous vehicle system’s modular design is depicted in the package diagram Figure. 7 . It divides related tasks into logical subsystems, including obstacle handling, color detection, and navigation. Sensors, actuators, and system logic are all coordinated by the Arduino UNO, which serves as the main controller. All active components are supported by the power supply, guaranteeing continuous functioning. The control, sensor, and actuation layers are neatly divided in this system.
C. Internal Body Diagram
The autonomous vehicle’s internal organization and communication flow are depicted in the internal block diagram Figure. 8 . The Line and Color Detection device processes sensor data from infrared, ultrasonic, and color sensors and sends pertinent signals to the Arduino UNO. Coordinated tire movement is the consequence of the Arduino controlling the motor depending on the processed inputs. This configuration demonstrates how perception, control, and actuation elements can be integrated.
D. Parametric Diagram
The autonomous vehicle system’s dependencies and limitations are depicted in the parametric diagram Figure. 9 It demonstrates how important features like line following and obstacle identification are influenced by sensor inputs and preset factors like track type and obstacle behavior. As the primary controller, the Arduino UNO processes inputs from infrared and ultrasonic sensors and regulates tire movement in response to system circumstances.


Fig. 7. Package Diagram


Fig. 8. Internal Body Diagram


Fig. 9. Parametric Diagram

VI. AUTONOMOUS NAVIGATION SIMULATION

We ran a number of simulations, starting with the electronic circuitry, to confirm the suggested autonomous car system’s operation prior to its actual deployment. We created and modelled the main electrical circuit using Multisim in order to confirm sensor integration, motor driver behavior, and power distribution.

A. Multisim Simulation

The autonomous vehicle’s circuit diagram is displayed in Figure. 10. An LM7805CT voltage regulator is used to regulate the system’s 11.1 V battery to 5 V so that all of its parts can operate safely. The wheels are driven by two DC motors that are managed by a motor driver. Two infrared sensor pairs each comprising an IR LED and phototransistor as well as pull-up and current limiting resistors for signal stability are used to accomplish line-following. While a color sensor recognizes the colors of objects, an ultrasonic sensor finds impediments. The ultrasonic sensor is rotated for scanning by a servo motor. The circuit has a switch to turn on the system and capacitors to smooth out power.With this configuration, the car can assess its surroundings and decide how to travel in real time.


Fig. 10. Multisim simulation

B. Tinkercad Simulation

Tinkercad, a virtual electronics platform that enables circuit design and testing without actual components, was used to simulate the hardware implementation of the autonomous car system Figure. 11 An H-bridge motor driver is used in the simulation to connect an Arduino UNO microcontroller to two DC motors, enabling directional control. IR sensors are placed for white line tracking, and an ultrasonic sensor (HC-SR04) is employed for obstacle detection. A 9V battery powers the system, and a breadboard is used in the setup to control connections and power distribution. Before the system is physically deployed, the simulation verifies its viability in the real world by validating motor control logic, sensor responses, and navigation behavior.

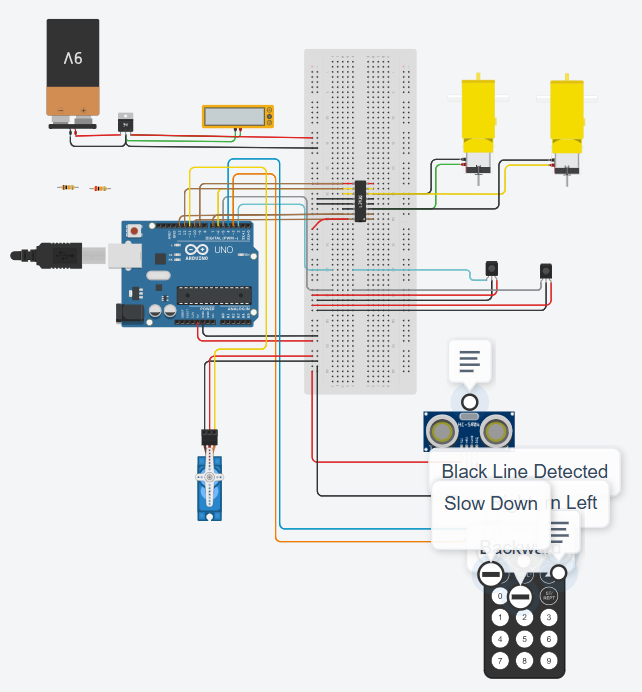
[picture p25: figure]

Fig. 11. Tinkercad simulation

C. Schematic View

A detailed schematic diagram Figure. 12 was created to depict the real hardware wiring of the autonomous car system after the Tinkercad simulation. All necessary electrical connections and component interconnections are depicted in the schematic. The central component is the Arduino UNO microcontroller (U1), which communicates with a servo motor (SERVO1) for scanning, an ultrasonic sensor (DIST1) for obstacle detection, and an H-Bridge motor driver (U5) for bidirectional motor control. A voltage regulator (U4) controls a 9V battery to provide steady 5V output. The direction movement is made possible by the motor driver, which controls the two DC motors (M1 and M2). For improved sensing and signal dependability, further modules are integrated, such as resistors and color sensors (U2, U3). Before the circuit is physically assembled, this schematic guarantees a precise implementation.


Fig. 12. Schematic View

VII. UPPAAL-BASED BEHAVIORAL MODELING AND SIMULATION

We used UPPAAL, a real-time system modeling tool for validating and verifying timed automata, to model the vehicle’s decision-making logic in order to guarantee dependable and secure behavior in autonomous navigation. The model is made up of multiple interacting timed automata, each of which is in charge of a distinct functional component of the behavior of the autonomous car.

A. Main Navigation Controller

The primary controller automaton in charge of guiding the vehicle’s fundamental movement behaviors is depicted in the Figure. 13. After the Move trigger, it moves from an initial SwitchOn state to MoveForward. The automata switches between states like TurnLeft, TurnRight, Stop, and obstaclerelated handling states like ColourCheck, OvertakeObstacle, and MoveTheObstacle in response to different sensor inputs. To ensure context-aware reactions, events like RedObstacle, GreenObstacle, or UnknownObstacle! initiate each transition.


Fig. 13. Main Navigation Controller

B. Obstacle Detection and Response Logic

When the system identifies a potential obstacle, it switches from the Obstacle free state to the Measuring Distance state (Move?) Figure. 14. It transitions to the Obstacle Detected state and then to Colour Check to determine the object’s color if an obstacle is verified (Obstacle?). The system determines what to do next, If the obstacle is red, the vehicle initiates an overtaking maneuver. If the obstacle is green, it performs a pushing action. For unknown color obstacles, the vehicle decides to park aside. The system reverts to the Obstacle free state and resumes regular function once the impediment has been effectively avoided or eliminated.

C. Left Side Behavior

The behavior of the left-side IR sensor is modeled by this automata. When the vehicle is not on line (CarNotOnLine), it turns on, checks the LeftIRon condition, makes a left correction (TurnLeft?) and then switches back to MoveForward Figure. 15.


Fig. 14. Obstacle Detection and Response Logic


Fig. 15. Left Side Behavior

D. Right Side Behavior
The opposite of the left IR behavior is this Figure. 16. Before going back to MoveForward, it reacts to CarNotOn-Line, checks the RightIRon signal, and orders a right turn (TurnRight?).


Fig. 16. Right Side Behavior

VIII. 3-D CAD MODEL OF THE AUTONOMOUS CAR PROTOTYPE
The completed 3D CAD design of the autonomous vehicle created for this project is shown in Figure. 17 Throughout the building process, the CAD model was a vital source of information that guaranteed precise component placement and spatial alignment. Important hardware elements like dualwheel differential drive systems, onboard controller mounts, ultrasonic sensors, and DC motors with encoders are all integrated into the design. Notably, the front panel sensor mount facilitates ambient awareness and obstacle recognition, both of which are critical for autonomous navigation activities. This design is carefully followed in the physical assembly, demonstrating the value of CAD modeling in system integration and iterative prototyping.


Fig. 17. 3-D CAD Model

IX. ELECTRONICS PARTS USED
An Arduino Uno microcontroller serves as the main component of the autonomous car’s electronics system, interacting with a variety of sensors and actuators. A TCS3200 color sensor for object categorization, an ultrasonic sensor for obstacle detection, and infrared sensors for line following are important parts. For directed scanning, the ultrasonic sensor is rotated by a servo motor. A 7.4 V or 11.1 V LiPo battery powers the L298N twin H-bridge motor driver, which controls the motors. Sensitive components receive a steady 5 V power supply thanks to a voltage regulator. A breadboard and jumper wires link all the components, allowing for modular and test-friendly assembly.
A. Arduino Uno R4
The Arduino Uno R4 Figure. 18 serves as its main controller, gathering input from sensors, processing it, and using actuators to initiate the required steps to allow movement. It is based on the Atmega328 microcontroller, which has an 8-bit RISC processor core and is a member of the Atmel family. As seen in Figure 16, the board has six analog input pins and fourteen digital GPIO pins. It communicates with a PC over a USB interface.The Arduino Uno is notable for its Atmega328P microcontroller, which has six analog input pins, 14 digital GPIO ports, and an 8-bit RISC CPU core. Because of these features, the Arduino Uno can effectively manage sensor inputs and control actuators, which makes it an essential part of the prototype’s operation. [1]
B. Ultrasonic Sensor
The Ultrasonic sensors Figure. 19 with a resolution of about 3 mm via ultrasonic signaling, this module is ideal for measuring distances ranging from 2 cm to 3 meters. The sensor starts measuring distance when a falling edge signal is applied to the trigger input. The distance measurement is then output as a PWM TTL signal from the echo pin. Applications including obstacle detection, distance measuring, liquid level monitoring, and other industrial uses are where the ultrasonic distance sensor excels. When activated, the ultrasonic transducer produces a 200 s burst of ultrasonic

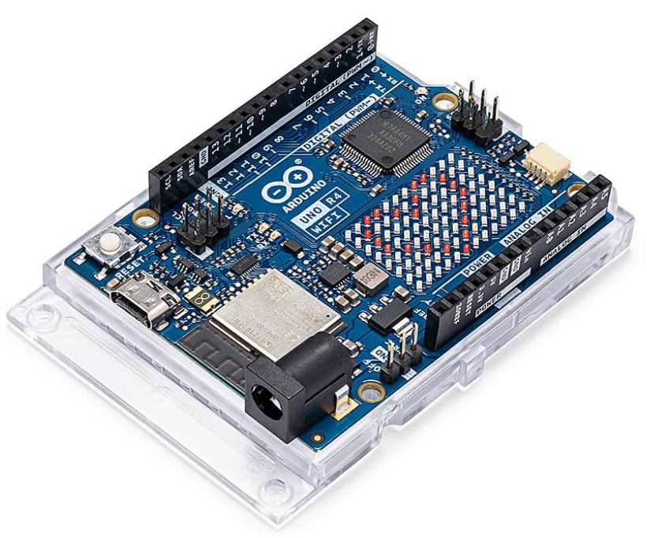
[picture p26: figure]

Fig. 18. Arduino Uno R4

waves at a frequency of 40 kHz, which produces 8 signal cycles at that time. A 10 s high-level pulse applied to the trigger input pin causes this emission. The echo output pin then swings high after this. The echo pin is pulled low when the microphone receives the reflected ultrasonic wave.The ultrasonic wave’s round-trip travel time from the transducer to the reflecting item and back is represented by the amount of time the echo pin stays high. It is possible to compute the distance to the object (as half the total traveled distance) by measuring this duration and assuming that sound travels at a constant speed in air. [2]


Fig. 19. Ultrasonic Sensor

C. IR Sensor
We make use of photodiodes, which are infrared (IR) transmitters and receivers Figure. 20 The photodiode serves as the receiver, identifying the reflected infrared signals and transmitting the relevant data to the microcontroller. The IR transmitter is an LED that emits infrared light. A detectable voltage shift occurs when the infrared light strikes a white surface because it is reflected back and picked up by the photodiode. On the other hand, when infrared light hits a black surface, it is absorbed instead of reflected, and the photodiode doesn’t get any signal [3].


Fig. 20. IR Sensor

D. Color Sensor
An array of photodiodes filtered for red, green, blue, and clear (unfiltered) light is how the TCS3200 color sensor works Figure. 21. The 4x4 matrix arrangement of these photodiodes enables precise measurement of light intensity throughout the visible spectrum. A current-to-frequency converter built inside the sensor produces a square wave signal whose frequency is proportional to the color’s intensity. The sensor can separate and measure the intensity of red, green, or blue light separately since the selection of particular color channels is digitally controlled. Depending on the color composition of the light, the matching photodiodes produce current when it reflects off a surface and enters the sensor. After that, this current is transformed into a frequency signal that a microcontroller can read and process to ascertain the surface’s hue. Because of this feature, the TCS3200 can be used in a number of applications, such as embedded robotics, industrial sorting systems, and color identification [4].


Fig. 21. Color Sensor

E. Motor Controller
The L298N is a dual-channel H-bridge motor driver that can provide both speed and direction control for two DC motors or one stepper motor Figure. ??. It can withstand peak currents of up to 2 A per channel and take motor supply voltages ranging from 5 V to 35 V (with an absolute maximum of 46 V).Two enable pins (ENA and ENB) receive PWM signals to control speed, and two logic inputs (IN1/IN2 for Motor A and IN3/IN4 for Motor B) control each H-bridge section by determining motor direction. If the input voltage is 12 V or less, the module’s onboard 78M05 linear regulator, which supplies a 5 V logic supply, can also power an external microcontroller.Integrated flyback diodes to guard against inductive voltage spikes and thermal shutdown to stop overheating are examples of protection features. For robotics, industrial actuation, and applications that require bidirectional motor control with changing speed, this makes the L298N module ideal [5].


Fig. 22. Motor Controller

F. Lippo Battery
A Conrad 7.4V 3000mAh 20C Eco-Line LiPo battery, illustrated in Figure. 23 , was used to supply power to the L298N motor driver. According to the manufacturer, the battery weighs approximately 210 grams [6].

Fig. 23. Lippo Battery

X. SOFTWARE IMPLEMENTATION
A. Initialization of Sensors and Actuators
To get the system ready for use, all the sensors and actuators are initialized in the Setup function of the Arduino code. This entails specifying the pin modes for servo motors, motors, color sensors, ultrasonic sensors, and infrared (IR) sensors. Depending on its purpose, each component is set up as either an input or an output. Additionally, serial communication is set up for monitoring and debugging. Pins for sensors were defined and initialized in the ‘setup()‘ function. Below is a snippet:

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

/ / IR s e n s o r s
pinMode ( R S , INPUT ) ;
/ / R i g h t IR s e n s o r pinMode ( L S , INPUT ) ;
/ / L e f t IR s e n s o r

/ / Motor c o n t r o l p i n s pinMode ( enA , OUTPUT ) ;

pinMode ( in1 , OUTPUT ) ; pinMode ( in2 , OUTPUT ) ; pinMode ( in3 , OUTPUT ) ; pinMode ( in4 , OUTPUT ) ; pinMode ( enB , OUTPUT ) ;

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

/ / Color s e n s o r
pinMode ( S0 , OUTPUT ) ;
pinMode ( S1 , OUTPUT ) ;
pinMode ( S2 , OUTPUT ) ;
pinMode ( S3 , OUTPUT ) ;
pinMode ( co lo rO ut , INPUT ) ; d i g i t a l W r i t e ( S0 , HIGH ) ;
d i g i t a l W r i t e ( S1 , LOW) ;

/ / Servo motor
s c a n S e r v o . a t t a c h ( s e r v o P i n ) ; s c a n S e r v o . w r i t e ( 5 0 ) ;
/ / S t a r t a t c e n t e r p o s i t i o n
d e l a y ( 3 0 0 ) ;
}
B. Movement Control Algorithms
Both programmed decision-making logic and sensor feedback regulate the autonomous vehicle’s movement. A black line on the track is followed by infrared (IR) sensors. In order to maintain alignment, the algorithm continuously examines the values from the left and right infrared sensors. If both detect the line, the robot advances; if only one does, it turns in that direction. An ultrasonic sensor tracks the separation between barriers.The car pauses and activates color detection when it detects an object within a predetermined threshold. Different operations are carried out based on the detected color: blue starts a parking routine by reversing, turning, and halting; green commences a forward-and-reverse bypass; and red initiates a right-side diversion and rejoining of the line. PWM signals are used to dynamically modify motor speed, ensuring smooth turning and obstacle-handling. The robot can move in both reactive and adaptable ways on its own thanks to these control systems.
C. Behavioral Decision Logic
The way the car changes states in response to sensor input is controlled by the behavioral decision logic. Under typical circumstances, the car uses infrared sensors to follow the line. The car shifts into ”approach” mode, cautiously approaching an obstruction when the ultrasonic sensor detects it within a predetermined distance. The system stops when it reaches a closer threshold and classifies the object using the color sensor.Depending on the color it senses, the robot does a certain action: blue parks the car and stops its motion, green is ignored after a brief sidestep, and red initiates a diversion.

If the line is lost at any of these stages, the system resets and starts an emergency pause. This decision logic ensures that the robot can adapt its actions dynamically to changes in the surroundings.

XI. FINAL AUTONOMOUS CAR PROTOTYPE

The autonomous car’s final prototype, depicted in Figure. 24 combines a number of sensors and electronic parts on a robotic platform with two wheels. The system is constructed on a wooden chassis and contains two DC motors that power the differential drive. A geared motor mount connects each motor to the wheels. By monitoring the surroundings, an ultrasonic sensor mounted on a servo motor at the front allows for dynamic obstacle detection. A TCS3200 color sensor is mounted directly beneath it to identify and categorize the colors of objects along the route. Infrared sensors positioned beneath the chassis and oriented to track black-and-white path transitions are used to implement line-following capabilities. Component integration and wiring are made easier by a single breadboard, which also makes connection testing and modification simple. An Arduino Uno manages the control logic, processing sensor inputs and adjusting actuators as necessary. The IR modules, ultrasonic sensor, color sensor, and motor driver (L298N), which is powered by a 7.4V 3000 mAh LiPo battery installed on the chassis, are among the several sensors that are connected via the wire. The arrangement is nonetheless modular and test-friendly, providing flexibility for upcoming enhancements or debugging even though the wiring is complicated due to the large number of interconnected components. Real-time experimentation and formal verification using UPPAAL models were used to validate this entire hardware system.


Fig. 24. Final Prototype

XII. GIT USAGE AND COLLABORATION

Project development was tracked using GitHub. Each member’s contribution should be explained.

Team Member | Number of Commits
Mohamed Abdo | 34
Md Ruhul Kuddus Saleh | 24
M Aamir Ejaz Ejaz | 11
Md Mostafizur Rahman | 10
Total | 114
TABLE I
GITHUB COMMITS BY TEAM MEMBERS

XIII. CONCLUSION AND FUTURE WORK

We successfully created an autonomous vehicle in this project that can identify the color of objects, follow lanes, and make decisions based on context. In addition to responding appropriately to recognized barriers based on their color starting an overtaking movement for red obstacles, pushing green objects, and parking aside for unknown colors the automobile consistently recognizes lane borders. These characteristics show how sensor inputs, real-time control logic, and fundamental autonomy can be integrated functionally. By switching from simple microcontroller platforms to more sophisticated hardware, such the Raspberry Pi, we hope to improve the system in subsequent work. This will allow for more processing power, adaptability, and the incorporation of machine learning models. In order to bring the system closer to real-world deployment standards, we also intend to add more professional-grade functionality and enhance the software architecture for improved scalability.

XIV. LIMITATIONS AND SENSOR CALIBRATION CHALLENGES

A significant problem with the color sensor’s capacity to identify the green spectrum was discovered during testing. In particular, the sensor was unable to identify green because of an inadequate output frequency, which needs to be kept at 100 percent (S0=H, S1=H) for precise detection see Fig
25. The issue most likely stems from power constraints that impact the output frequency scaling of the sensor. Specifically for the green photodiode option (S2=H, S3=H), the system needs an external power supply to guarantee a steady and dependable output frequency for accurate color discrimination. This emphasizes how crucial proper power management and calibration are for applications that rely on sensors.

Fig. 25. Color Table

ACKNOWLEDGMENT

This project was made possible through the invaluable support, resources, and expertise provided by Hamm-Lippstadt University of Applied Sciences. We would like to extend our sincere gratitude to Prof. Dr. Stefan Henkler, Prof. Faezeh

Pasandideh, and Mr. G. Wahrmann for their unwavering guidance, commitment, and constructive feedback, which played a crucial role in the continuous improvement of our work.

REFERENCES

[1] “Uno | R3,” | Arduino. | [Online]. | Available:
https://docs.arduino.cc/hardware/uno-rev3/. [Accessed: Jun. 27, 2024].
[2] Joy-IT, “KY-050 ultrasonic distance sensor,” SensorKit. [Online]. Available: https://sensorkit.joy-it.net/en/sensors/ky-050. [Accessed: Jun. 27, 2024]
[3] https://www.irjet.net/archives/V7/i2/IRJET-V7I2379.pdf
[4] “TCS3200 | Programmable | Color | Light-to-Frequency | Converter,”
Texas | Advanced | Optoelectronic | Solutions | (TAOS), | [Online].
Available: https://www.mouser.com/catalog/specsheets/tcs3200-e11.pdf. [Accessed: Jun. 27, 2024]
[5] L298N Dual H-Bridge Motor Driver, Handson Technology. [Online]. Available: https://www.handsontec.com/dataspecs/L298N
[6] “Buy Conrad Energy Scale Model Battery Pack (LIPO) 7.4 V 5500 mAh no. of cells: 2 20 C Softcase XT90,” Conrad Electronic. [Online]. Available: https://www.conrad.com/en/p/conrad-energy-scale-modelbattery-pack-lipo-7-4-v-5500-mah-no-of-cells-2-20-c-softcase-xt90-1344152.html. [Accessed: Jun. 27, 2024]

DECLARATION OF ORIGINALITY

We hereby declare that this report is our own work and that we have acknowledged all sources used.

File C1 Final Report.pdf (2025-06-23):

# Autonomous Line-Following Vehicle with Integrated Obstacle and Color Detection System

Mohamed Abdo∗

, M Aamir Ejaz Ejaz∗

,Md Ruhul Kuddus Saleh∗

, Md Mostafizur Rahman∗
∗Systems Engineering and Prototyping, BSc Electronic Engineering Hochschule Hamm-Lippstadt, Lippstadt, Germany {mohamed-sayed-mohamed.abdo, muhammad-aamir.ejaz-ejaz, md-ruhul-kuddus.saleh, md-mostafizur.rahman}@stud.hshl.de

Abstract—In this study, our team’s line-following vehicle prototype is shown. The robot can follow designated routes, recognize and detect obstacles, identify their color, and react appropriately based on that color. The project’s objectives, hardware design, electronic components, and programming strategies are all examined in this article in order to accomplish the intended functionality. Additionally, it displays the tasks finished, tests conducted, and experiments conducted during the semester in order to evaluate and validate the efficacy of the system.
Index Terms—Line follower robot,
I. INTRODUCTION

This project presents an autonomous line-following vehicle capable of obstacle detection and color-based decision-making. Using an Arduino UNO R4, IR sensors, ultrasonic sensors, and a TCS3200 color sensor, the vehicle follows a black line and reacts to obstacles intelligently. It overtakes red objects, pushes green, and performs park maneuver if the object color is unknown. A servo-mounted ultrasonic sensor enhances obstacle scanning, while a voltage monitoring system adjusts speed for optimal performance. This project integrates embedded systems, sensor fusion, and robotics control, offering a practical model for intelligent navigation.

II. SYSTEM DESIGN AND ENGINEERING

The system design of the autonomous vehicle integrates hardware components and embedded logic to achieve efficient and adaptive navigation. The core controller, an Arduino UNO R4, manages sensor data processing and motor control. Two infrared sensors are positioned to detect the black line path, enabling continuous line-following behavior.
For obstacle detection, an ultrasonic sensor is mounted on a servo motor, allowing dynamic scanning of the surroundings. This rotating sensor increases detection accuracy and helps in planning overtaking maneuvers. A TCS3200 color sensor is used to identify the color of the obstacle, determining how the vehicle should react: when the car detects red, it starts to overtake, when it detects green, it pushes, and when it detects an unidentified object, it parks.
Motor control is achieved through an L298N motor driver, which provides bidirectional movement and turning. A voltage monitoring system adjusts the car’s speed based on battery levels to maintain consistent performance. The coordination between sensors, actuators, and programmed logic forms a robust embedded control system for real-time decision-making.

III. PROTOTYPING AND DESIGN

A. Electronic Components
The vehicle’s control system is centered around an Arduino UNO R4, which manages inputs from sensors and outputs to motors. Two infrared (IR) sensors are mounted at the front underside of the chassis to track the black line on the ground. An ultrasonic sensor, mounted on a vertical plate, provides distance measurements for obstacle detection. The TCS3200 color sensor is positioned close to the ground to accurately detect object color. An L298N motor driver is used for bidirectional control of the DC motors, and a voltage divider circuit is included to monitor battery levels in real-time.
B. Virtual and Physical Prototypes
The design process began with virtual prototyping using SolidWorks to visualize the mechanical structure and component placement. The virtual prototype allowed optimization of sensor angles, wheel spacing, and clearances before committing to physical assembly. After finalizing the CAD model, the physical prototype was built using a two-level chassis made from lightweight materials to separate the sensor and control layers. Multiple iterations were conducted to test wiring layout, sensor performance, and motor response.
C. Hardware Assembly
The hardware was mounted as per the CAD model. The ultrasonic sensor is fixed on a frontal panel with symmetrical alignment to maximize forward detection range. Below the base plate, the IR sensors are angled slightly downward for optimal ground visibility. The servo motor controlling the ultrasonic scanner is centrally positioned to sweep the surroundings effectively. All electronic components, including the Arduino board, motor driver, and battery pack, are mounted securely to minimize vibrations and maintain system stability during motion. The structured layout ensures efficient wiring, accessibility for maintenance, and protection of components during operation.

IV. SYSML DIAGRAMS

A. Requirement Diagram
The criteria for the autonomous vehicle system are shown in Figure 1 Line-following, dynamic speed control, and color-based obstacle handling are all supported. The Unknown colors cause the car to park, green starts a push action, and red starts an overtaking maneuver. Figure 1 displays the requirements for the autonomous car system. Line-following, dynamic speed control, and color-based obstacle handling are all supported by the system. Green barriers are pushed aside, red starts a detour, and unidentified hues result in a parking maneuver. The sensor-driven, modular architecture of the design guarantees dependable and secure navigation.


Fig. 1. Requirement Diagram

B. State Machine Diagram

A state machine model is used in Figure. 2 to depict the control logic of the autonomous vehicle in order to support this behavior. The system starts in idle mode and then switches to line-following navigation. The car branches its behavior based on color input when it detects obstacles: green starts a push action, red starts a detour, and unknown colors force the car to halt and park. When a task is finished or unrecoverable situations are encountered, the system enters a standstill state. In order to preserve operational safety, emergency transitions also manage situations like line loss.


Fig. 2. State Machine Diagram

C. Activity Diagram
The activity diagram in Figure. 3shows the autonomous vehicle’s operating flow in accordance with the state machine logic. By modifying its motion in response to line detection, the system initiates autonomous navigation. It continuously recognizes and assesses the color of obstacles it detects as it moves forward. Unknown colors cause the car to stop and park, green starts a push maneuver, and red starts a detour that is followed by a return to the main path. Until the route is successfully finished or the system is manually stopped, this process keeps on.


Fig. 3. Activity Diagram

D. Use Case Diagram
The use case diagram Figure. 4 depicts the main characteristics of the Autonomous Path-Following and Obstacle Detection System. As the primary external actors, the team members engage with the system by turning it on and off using the switch on/off feature. The technology automatically navigates once it is turned on, detecting lines, obstacles, and regulating speed. Using line-following logic, the navigation process facilitates directional decisions like turning left or right. The system uses obstacle detection to make color-based decisions: unknown colors, as specified by the modified system behavior, force the vehicle to stop and park; green obstacles commence a push maneuver; and red obstacles start an avoidance or detour sequence. Furthermore, under the speed-regulated navigation mode, the system can follow predefined path patterns like oval and figure-eight routes.
E. Sequence Diagram
The sequence diagram Figure.5 shows how the various parts of the system interact during autonomous navigation. Line detection and sensor activation are started when the user turns on the system. The car continuously looks for obstructions as it travels forward. Green obstacles are pushed aside, red obstacles cause an overtaking action, and unknown colors cause the system to halt and park. The system employs the color sensor to classify obstacles when it detects them. In


Fig. 4. Use Case Diagram

the meantime, motor control uses input from the servo’s area scan to dynamically modify speed and direction. Smooth, autonomous navigation is made possible by this time-sequenced interaction, which guarantees real-time decision-making.


Fig. 5. Sequence Diagram

V. STRUCTURE DIAGRAMS
The autonomous vehicle system’s static architecture is specified via structure diagrams. They show how hardware and software components are arranged, relate to one another, and work together to support navigation, obstacle detection, and decision-making features.
A. Block Definition Diagram
Moving onto the structure part of the SysML,we start with the Block Definition Diagram (BDD). The BDD in Figure. 6 is used to model the structural composition of the autonomous vehicle system, emphasizing how the system is organized and broken down into functional parts. It demonstrates how the two main subsystems safety and navigation are further broken down into essential elements like line detection, obstacle avoidance, and route selection. Because these functional blocks are linked to hardware elements like motors, sensors, and the Arduino UNO, they show how software logic is translated onto the physical architecture. The way that different components work together to enable the vehicle’s autonomous behavior is clearly understood thanks to this structural representation.


Fig. 6. Block Definition Diagram

B. Package Diagram
The autonomous vehicle system’s modular design is depicted in the package diagram Figure. 7 . It divides related tasks into logical subsystems, including obstacle handling, color detection, and navigation. Sensors, actuators, and system logic are all coordinated by the Arduino UNO, which serves as the main controller. All active components are supported by the power supply, guaranteeing continuous functioning. The control, sensor, and actuation layers are neatly divided in this system.
C. Internal Body Diagram
The autonomous vehicle’s internal organization and communication flow are depicted in the internal block diagram Figure. 8 . The Line and Color Detection device processes sensor data from infrared, ultrasonic, and color sensors and sends pertinent signals to the Arduino UNO. Coordinated tire movement is the consequence of the Arduino controlling the motor depending on the processed inputs. This configuration demonstrates how perception, control, and actuation elements can be integrated.
D. Parametric Diagram
The autonomous vehicle system’s dependencies and limitations are depicted in the parametric diagram Figure. 9 It demonstrates how important features like line following and obstacle identification are influenced by sensor inputs and preset factors like track type and obstacle behavior. As the primary controller, the Arduino UNO processes inputs from infrared and ultrasonic sensors and regulates tire movement in response to system circumstances.


Fig. 7. Package Diagram


Fig. 8. Internal Body Diagram


Fig. 9. Parametric Diagram

VI. AUTONOMOUS NAVIGATION SIMULATION

We ran a number of simulations, starting with the electronic circuitry, to confirm the suggested autonomous car system’s operation prior to its actual deployment. We created and modelled the main electrical circuit using Multisim in order to confirm sensor integration, motor driver behavior, and power distribution.

A. Multisim Simulation

The autonomous vehicle’s circuit diagram is displayed in Figure. 10. An LM7805CT voltage regulator is used to regulate the system’s 11.1 V battery to 5 V so that all of its parts can operate safely. The wheels are driven by two DC motors that are managed by a motor driver. Two infrared sensor pairs each comprising an IR LED and phototransistor as well as pull-up and current limiting resistors for signal stability are used to accomplish line-following. While a color sensor recognizes the colors of objects, an ultrasonic sensor finds impediments. The ultrasonic sensor is rotated for scanning by a servo motor. The circuit has a switch to turn on the system and capacitors to smooth out power.With this configuration, the car can assess its surroundings and decide how to travel in real time.


Fig. 10. Multisim simulation

B. Tinkercad Simulation

Tinkercad, a virtual electronics platform that enables circuit design and testing without actual components, was used to simulate the hardware implementation of the autonomous car system Figure. 11 An H-bridge motor driver is used in the simulation to connect an Arduino UNO microcontroller to two DC motors, enabling directional control. IR sensors are placed for white line tracking, and an ultrasonic sensor (HC-SR04) is employed for obstacle detection. A 9V battery powers the system, and a breadboard is used in the setup to control connections and power distribution. Before the system is physically deployed, the simulation verifies its viability in the real world by validating motor control logic, sensor responses, and navigation behavior.


Fig. 11. Tinkercad simulation

C. Schematic View

A detailed schematic diagram Figure. 12 was created to depict the real hardware wiring of the autonomous car system after the Tinkercad simulation. All necessary electrical connections and component interconnections are depicted in the schematic. The central component is the Arduino UNO microcontroller (U1), which communicates with a servo motor (SERVO1) for scanning, an ultrasonic sensor (DIST1) for obstacle detection, and an H-Bridge motor driver (U5) for bidirectional motor control. A voltage regulator (U4) controls a 9V battery to provide steady 5V output. The direction movement is made possible by the motor driver, which controls the two DC motors (M1 and M2). For improved sensing and signal dependability, further modules are integrated, such as resistors and color sensors (U2, U3). Before the circuit is physically assembled, this schematic guarantees a precise implementation.


Fig. 12. Schematic View

VII. UPPAAL-BASED BEHAVIORAL MODELING AND SIMULATION

We used UPPAAL, a real-time system modeling tool for validating and verifying timed automata, to model the vehicle’s decision-making logic in order to guarantee dependable and secure behavior in autonomous navigation. The model is made up of multiple interacting timed automata, each of which is in charge of a distinct functional component of the behavior of the autonomous car.

A. Main Navigation Controller

The primary controller automaton in charge of guiding the vehicle’s fundamental movement behaviors is depicted in the Figure. 13. After the Move trigger, it moves from an initial SwitchOn state to MoveForward. The automata switches between states like TurnLeft, TurnRight, Stop, and obstaclerelated handling states like ColourCheck, OvertakeObstacle, and MoveTheObstacle in response to different sensor inputs. To ensure context-aware reactions, events like RedObstacle, GreenObstacle, or UnknownObstacle! initiate each transition.


Fig. 13. Main Navigation Controller

B. Obstacle Detection and Response Logic

When the system identifies a potential obstacle, it switches from the Obstacle free state to the Measuring Distance state (Move?) Figure. 14. It transitions to the Obstacle Detected state and then to Colour Check to determine the object’s color if an obstacle is verified (Obstacle?). The system determines what to do next, If the obstacle is red, the vehicle initiates an overtaking maneuver. If the obstacle is green, it performs a pushing action. For unknown color obstacles, the vehicle decides to park aside. The system reverts to the Obstacle free state and resumes regular function once the impediment has been effectively avoided or eliminated.

C. Left Side Behavior

The behavior of the left-side IR sensor is modeled by this automata. When the vehicle is not on line (CarNotOnLine), it turns on, checks the LeftIRon condition, makes a left correction (TurnLeft?) and then switches back to MoveForward Figure. 15.


Fig. 14. Obstacle Detection and Response Logic


Fig. 15. Left Side Behavior

D. Right Side Behavior
The opposite of the left IR behavior is this Figure. 16. Before going back to MoveForward, it reacts to CarNotOn-Line, checks the RightIRon signal, and orders a right turn (TurnRight?).


Fig. 16. Right Side Behavior

VIII. 3-D CAD MODEL OF THE AUTONOMOUS CAR PROTOTYPE
The completed 3D CAD design of the autonomous vehicle created for this project is shown in Figure. 17 Throughout the building process, the CAD model was a vital source of information that guaranteed precise component placement and spatial alignment. Important hardware elements like dualwheel differential drive systems, onboard controller mounts, ultrasonic sensors, and DC motors with encoders are all integrated into the design. Notably, the front panel sensor mount facilitates ambient awareness and obstacle recognition, both of which are critical for autonomous navigation activities. This design is carefully followed in the physical assembly, demonstrating the value of CAD modeling in system integration and iterative prototyping.


Fig. 17. 3-D CAD Model

IX. ELECTRONICS PARTS USED
An Arduino Uno microcontroller serves as the main component of the autonomous car’s electronics system, interacting with a variety of sensors and actuators. A TCS3200 color sensor for object categorization, an ultrasonic sensor for obstacle detection, and infrared sensors for line following are important parts. For directed scanning, the ultrasonic sensor is rotated by a servo motor. A 7.4 V or 11.1 V LiPo battery powers the L298N twin H-bridge motor driver, which controls the motors. Sensitive components receive a steady 5 V power supply thanks to a voltage regulator. A breadboard and jumper wires link all the components, allowing for modular and test-friendly assembly.
A. Arduino Uno R4
The Arduino Uno R4 Figure. 18 serves as its main controller, gathering input from sensors, processing it, and using actuators to initiate the required steps to allow movement. It is based on the Atmega328 microcontroller, which has an 8-bit RISC processor core and is a member of the Atmel family. As seen in Figure 16, the board has six analog input pins and fourteen digital GPIO pins. It communicates with a PC over a USB interface.The Arduino Uno is notable for its Atmega328P microcontroller, which has six analog input pins, 14 digital GPIO ports, and an 8-bit RISC CPU core. Because of these features, the Arduino Uno can effectively manage sensor inputs and control actuators, which makes it an essential part of the prototype’s operation. [1]
B. Ultrasonic Sensor
The Ultrasonic sensors Figure. 19 with a resolution of about 3 mm via ultrasonic signaling, this module is ideal for measuring distances ranging from 2 cm to 3 meters. The sensor starts measuring distance when a falling edge signal is applied to the trigger input. The distance measurement is then output as a PWM TTL signal from the echo pin. Applications including obstacle detection, distance measuring, liquid level monitoring, and other industrial uses are where the ultrasonic distance sensor excels. When activated, the ultrasonic transducer produces a 200 s burst of ultrasonic


Fig. 18. Arduino Uno R4

waves at a frequency of 40 kHz, which produces 8 signal cycles at that time. A 10 s high-level pulse applied to the trigger input pin causes this emission. The echo output pin then swings high after this. The echo pin is pulled low when the microphone receives the reflected ultrasonic wave.The ultrasonic wave’s round-trip travel time from the transducer to the reflecting item and back is represented by the amount of time the echo pin stays high. It is possible to compute the distance to the object (as half the total traveled distance) by measuring this duration and assuming that sound travels at a constant speed in air. [2]


Fig. 19. Ultrasonic Sensor

C. IR Sensor
We make use of photodiodes, which are infrared (IR) transmitters and receivers Figure. 20 The photodiode serves as the receiver, identifying the reflected infrared signals and transmitting the relevant data to the microcontroller. The IR transmitter is an LED that emits infrared light. A detectable voltage shift occurs when the infrared light strikes a white surface because it is reflected back and picked up by the photodiode. On the other hand, when infrared light hits a black surface, it is absorbed instead of reflected, and the photodiode doesn’t get any signal [3].


Fig. 20. IR Sensor

D. Color Sensor
An array of photodiodes filtered for red, green, blue, and clear (unfiltered) light is how the TCS3200 color sensor works Figure. 21. The 4x4 matrix arrangement of these photodiodes enables precise measurement of light intensity throughout the visible spectrum. A current-to-frequency converter built inside the sensor produces a square wave signal whose frequency is proportional to the color’s intensity. The sensor can separate and measure the intensity of red, green, or blue light separately since the selection of particular color channels is digitally controlled. Depending on the color composition of the light, the matching photodiodes produce current when it reflects off a surface and enters the sensor. After that, this current is transformed into a frequency signal that a microcontroller can read and process to ascertain the surface’s hue. Because of this feature, the TCS3200 can be used in a number of applications, such as embedded robotics, industrial sorting systems, and color identification [4].


Fig. 21. Color Sensor

E. Motor Controller
The L298N is a dual-channel H-bridge motor driver that can provide both speed and direction control for two DC motors or one stepper motor Figure. ??. It can withstand peak currents of up to 2 A per channel and take motor supply voltages ranging from 5 V to 35 V (with an absolute maximum of 46 V).Two enable pins (ENA and ENB) receive PWM signals to control speed, and two logic inputs (IN1/IN2 for Motor A and IN3/IN4 for Motor B) control each H-bridge section by determining motor direction. If the input voltage is 12 V or less, the module’s onboard 78M05 linear regulator, which supplies a 5 V logic supply, can also power an external microcontroller.Integrated flyback diodes to guard against inductive voltage spikes and thermal shutdown to stop overheating are examples of protection features. For robotics, industrial actuation, and applications that require bidirectional motor control with changing speed, this makes the L298N module ideal [5].


Fig. 22. Motor Controller

F. Lippo Battery
A Conrad 7.4V 3000mAh 20C Eco-Line LiPo battery, illustrated in Figure. 23 , was used to supply power to the L298N motor driver. According to the manufacturer, the battery weighs approximately 210 grams [6].

Fig. 23. Lippo Battery

X. SOFTWARE IMPLEMENTATION
A. Initialization of Sensors and Actuators
To get the system ready for use, all the sensors and actuators are initialized in the Setup function of the Arduino code. This entails specifying the pin modes for servo motors, motors, color sensors, ultrasonic sensors, and infrared (IR) sensors. Depending on its purpose, each component is set up as either an input or an output. Additionally, serial communication is set up for monitoring and debugging. Pins for sensors were defined and initialized in the ‘setup()‘ function. Below is a snippet:

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

/ / IR s e n s o r s
pinMode ( R S , INPUT ) ;
/ / R i g h t IR s e n s o r pinMode ( L S , INPUT ) ;
/ / L e f t IR s e n s o r

/ / Motor c o n t r o l p i n s pinMode ( enA , OUTPUT ) ;

pinMode ( in1 , OUTPUT ) ; pinMode ( in2 , OUTPUT ) ; pinMode ( in3 , OUTPUT ) ; pinMode ( in4 , OUTPUT ) ; pinMode ( enB , OUTPUT ) ;

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

/ / Color s e n s o r
pinMode ( S0 , OUTPUT ) ;
pinMode ( S1 , OUTPUT ) ;
pinMode ( S2 , OUTPUT ) ;
pinMode ( S3 , OUTPUT ) ;
pinMode ( co lo rO ut , INPUT ) ; d i g i t a l W r i t e ( S0 , HIGH ) ;
d i g i t a l W r i t e ( S1 , LOW) ;

/ / Servo motor
s c a n S e r v o . a t t a c h ( s e r v o P i n ) ; s c a n S e r v o . w r i t e ( 5 0 ) ;
/ / S t a r t a t c e n t e r p o s i t i o n
d e l a y ( 3 0 0 ) ;
}
B. Movement Control Algorithms
Both programmed decision-making logic and sensor feedback regulate the autonomous vehicle’s movement. A black line on the track is followed by infrared (IR) sensors. In order to maintain alignment, the algorithm continuously examines the values from the left and right infrared sensors. If both detect the line, the robot advances; if only one does, it turns in that direction. An ultrasonic sensor tracks the separation between barriers.The car pauses and activates color detection when it detects an object within a predetermined threshold. Different operations are carried out based on the detected color: blue starts a parking routine by reversing, turning, and halting; green commences a forward-and-reverse bypass; and red initiates a right-side diversion and rejoining of the line. PWM signals are used to dynamically modify motor speed, ensuring smooth turning and obstacle-handling. The robot can move in both reactive and adaptable ways on its own thanks to these control systems.
C. Behavioral Decision Logic
The way the car changes states in response to sensor input is controlled by the behavioral decision logic. Under typical circumstances, the car uses infrared sensors to follow the line. The car shifts into ”approach” mode, cautiously approaching an obstruction when the ultrasonic sensor detects it within a predetermined distance. The system stops when it reaches a closer threshold and classifies the object using the color sensor.Depending on the color it senses, the robot does a certain action: blue parks the car and stops its motion, green is ignored after a brief sidestep, and red initiates a diversion.

If the line is lost at any of these stages, the system resets and starts an emergency pause. This decision logic ensures that the robot can adapt its actions dynamically to changes in the surroundings.

XI. FINAL AUTONOMOUS CAR PROTOTYPE

The autonomous car’s final prototype, depicted in Figure. 24 combines a number of sensors and electronic parts on a robotic platform with two wheels. The system is constructed on a wooden chassis and contains two DC motors that power the differential drive. A geared motor mount connects each motor to the wheels. By monitoring the surroundings, an ultrasonic sensor mounted on a servo motor at the front allows for dynamic obstacle detection. A TCS3200 color sensor is mounted directly beneath it to identify and categorize the colors of objects along the route. Infrared sensors positioned beneath the chassis and oriented to track black-and-white path transitions are used to implement line-following capabilities. Component integration and wiring are made easier by a single breadboard, which also makes connection testing and modification simple. An Arduino Uno manages the control logic, processing sensor inputs and adjusting actuators as necessary. The IR modules, ultrasonic sensor, color sensor, and motor driver (L298N), which is powered by a 7.4V 3000 mAh LiPo battery installed on the chassis, are among the several sensors that are connected via the wire. The arrangement is nonetheless modular and test-friendly, providing flexibility for upcoming enhancements or debugging even though the wiring is complicated due to the large number of interconnected components. Real-time experimentation and formal verification using UPPAAL models were used to validate this entire hardware system.


Fig. 24. Final Prototype

XII. GIT USAGE AND COLLABORATION

Project development was tracked using GitHub. Each member’s contribution should be explained.

Team Member | Number of Commits
Mohamed Abdo | 34
Md Ruhul Kuddus Saleh | 24
M Aamir Ejaz Ejaz | 11
Md Mostafizur Rahman | 10
Total | 114
TABLE I
GITHUB COMMITS BY TEAM MEMBERS

XIII. CONCLUSION AND FUTURE WORK

We successfully created an autonomous vehicle in this project that can identify the color of objects, follow lanes, and make decisions based on context. In addition to responding appropriately to recognized barriers based on their color starting an overtaking movement for red obstacles, pushing green objects, and parking aside for unknown colors the automobile consistently recognizes lane borders. These characteristics show how sensor inputs, real-time control logic, and fundamental autonomy can be integrated functionally. By switching from simple microcontroller platforms to more sophisticated hardware, such the Raspberry Pi, we hope to improve the system in subsequent work. This will allow for more processing power, adaptability, and the incorporation of machine learning models. In order to bring the system closer to real-world deployment standards, we also intend to add more professional-grade functionality and enhance the software architecture for improved scalability.

XIV. LIMITATIONS AND SENSOR CALIBRATION CHALLENGES

A significant problem with the color sensor’s capacity to identify the green spectrum was discovered during testing. In particular, the sensor was unable to identify green because of an inadequate output frequency, which needs to be kept at 100 percent (S0=H, S1=H) for precise detection see Fig
25. The issue most likely stems from power constraints that impact the output frequency scaling of the sensor. Specifically for the green photodiode option (S2=H, S3=H), the system needs an external power supply to guarantee a steady and dependable output frequency for accurate color discrimination. This emphasizes how crucial proper power management and calibration are for applications that rely on sensors.

Fig. 25. Color Table

ACKNOWLEDGMENT

This project was made possible through the invaluable support, resources, and expertise provided by Hamm-Lippstadt University of Applied Sciences. We would like to extend our sincere gratitude to Prof. Dr. Stefan Henkler, Prof. Faezeh

Pasandideh, and Mr. G. Wahrmann for their unwavering guidance, commitment, and constructive feedback, which played a crucial role in the continuous improvement of our work.

REFERENCES

[1] “Uno | R3,” | Arduino. | [Online]. | Available:
https://docs.arduino.cc/hardware/uno-rev3/. [Accessed: Jun. 27, 2024].
[2] Joy-IT, “KY-050 ultrasonic distance sensor,” SensorKit. [Online]. Available: https://sensorkit.joy-it.net/en/sensors/ky-050. [Accessed: Jun. 27, 2024]
[3] https://www.irjet.net/archives/V7/i2/IRJET-V7I2379.pdf
[4] “TCS3200 | Programmable | Color | Light-to-Frequency | Converter,”
Texas | Advanced | Optoelectronic | Solutions | (TAOS), | [Online].
Available: https://www.mouser.com/catalog/specsheets/tcs3200-e11.pdf. [Accessed: Jun. 27, 2024]
[5] L298N Dual H-Bridge Motor Driver, Handson Technology. [Online]. Available: https://www.handsontec.com/dataspecs/L298N
[6] “Buy Conrad Energy Scale Model Battery Pack (LIPO) 7.4 V 5500 mAh no. of cells: 2 20 C Softcase XT90,” Conrad Electronic. [Online]. Available: https://www.conrad.com/en/p/conrad-energy-scale-modelbattery-pack-lipo-7-4-v-5500-mah-no-of-cells-2-20-c-softcase-xt90-1344152.html. [Accessed: Jun. 27, 2024]

DECLARATION OF ORIGINALITY

We hereby declare that this report is our own work and that we have acknowledged all sources used.

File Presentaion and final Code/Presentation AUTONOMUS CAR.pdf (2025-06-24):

# SYSTEM ENGINEERING


&

# PROTOTYPING

## Team: C1

Members:
- Md Mostafizur Rahman
- Mohamed Abdo
- Md Ruhul Kuddus Saleh
- M Amir Ejaz


# SYSTEM OVERVIEW

- Developing an autonomous car using Arduino.
- Integrates ultrasonic sensors for obstacle detection
- Infrared sensors for line following
- Uses color sensor for for color detection
- DC motors drive the car.
- Servo motor for obstacle removal

# COMPONENTS



# TEAM CONTRIBUTION

&

# GIT COMMITS

https://github.com/MoAbdoHSHL/Robotic_Car_TeamC1-HSHL (https://github.com/MoAbdoHSHL/Robotic_Car_TeamC1-HSHL)


# Requirement

- Follow a lane
- Drive different routes
- Optimize Voltage and Speed
- Detect Obstacles
- Detect Different color and take actions
- Push / Overtake an obstacle
- Park the car

# STATE MACHINE DIAGRAM


- Starts with "Power ON„
- Moves to "Idle Forward„
- Detects obstacles and color.
- Responds (push, avoid, or park).
- Handles turning, interrupts, and emergencies.


# ACTIVITY DIAGRAM

- Starts with autonomous navigation.
- Decides to move left, right, or forward.
- Checks if it’s on the path.
- Detects obstacles & responds (avoid, push, or stop).
- Ends by stopping or parking.

# 3D PRINTED PARTS


Switch Holder

IR Holder | Motor Holder

Ultrasonic Holder

Color & Servo Holder | Battery Holder

# FINAL


# DESIGN


# UPPAL SIMULATION


# VOLTAGE & CURRENT MEASUREMENT

- Uses motors, sensors, and a battery.
- voltage regulator and capacitors.
- IR and color sensors detect obstacles.
- Power flows through regulated paths.

# SCHEMATIC VIEW ON TINKERCAD

- wiring connectins.
- Arduino controls

sensors and motors

- Initial Code testing


https://www.tinkercad.com/things/dzwxTrQqEL3-swanky-snaget/editel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 (https://www.tinkercad.com/things/dzwxTrQqEL3-swanky-snaget/editel)

# LANE FOLLOWING


# PID FOR OPTIMIZING SYSTEM


# OBSTACLE DETECTION


# COLOR DETECTION & REACTION


Blue Color Detected and Push the Object

# COLOR DETECTION & REACTION


Red Color Detected and turn 90° to avoid the Object & return back to lane

# CHALLENGES & OBSERVATIONS

Blue Detected; Red Detected; Green Not Detected

“TCS3200 Programmable Color Light-to-Frequency Converter,” Texas Advanced Optoelectronic Solutions (TAOS), [Online]. Available: https://www.mouser.com/catalog/specsheets/tcs3200-e11.pdf. [Accessed: Jun. 27, 2024]

# THANK YOU FOR YOUR TIME ☺


# QUESTIONS OR FEEDBACKS?

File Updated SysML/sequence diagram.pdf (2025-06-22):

Motor Controller; Autonomous System Vehicle; IR Sensor; Ultrasonic sensor; Servo Motor User; Sensors Module; Send Signals Take Action; Sensors on; Check for black line; Take Action / Not Detected; Adjust Speed and Follow Oval & Eight; Start Navigation; Color Sensor; Check Color; Stop Navigation; Scan 90°; Red/Green/Unknown Take Action; Scan Object

## sd [Autonomous Path-Following and Obstacle Detection System]

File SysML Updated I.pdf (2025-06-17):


1

# Prototyping and System Engineering

## SysML

Group C1: Mohamed Abdo, Md Ruhul, Md Rahman, Muhammad Aamir

Requirement: Autonomous Path-Following and Obstacle Detection System


2

Behaviour Diagrams:
Use Case:


3

State Machine:


4

Activity Diagram:


5

Sequence Diagram:


6

Structure Diagram:
Block definition Diagram


7

Package Diagram:


8

Internal Body Diagram:


9

Paramentric Diagram:

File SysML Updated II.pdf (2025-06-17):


1

# Prototyping and System Engineering

## SysML

Group C1: Mohamed Abdo, Md Ruhul, Md Rahman, Muhammad Aamir

Requirement: Autonomous Path-Following and Obstacle Detection System


2

Behaviour Diagrams:
Use Case:


3

State Machine:


4

Activity Diagram:


5

Sequence Diagram:


6

Structure Diagram:
Block definition Diagram


7

Package Diagram:


8

Internal Body Diagram:


9

Paramentric Diagram:

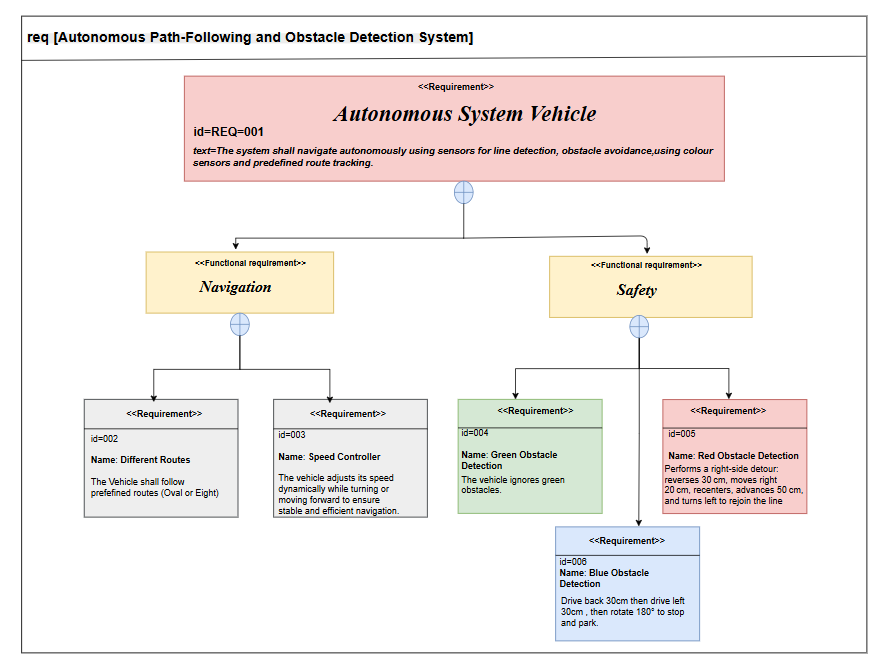
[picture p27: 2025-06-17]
Task-3/SysML/Requirement.png

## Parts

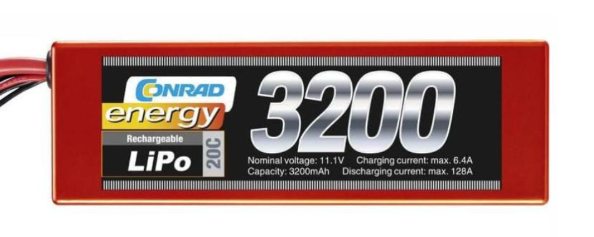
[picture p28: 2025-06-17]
Task-4/Components/Lipo Battery.png

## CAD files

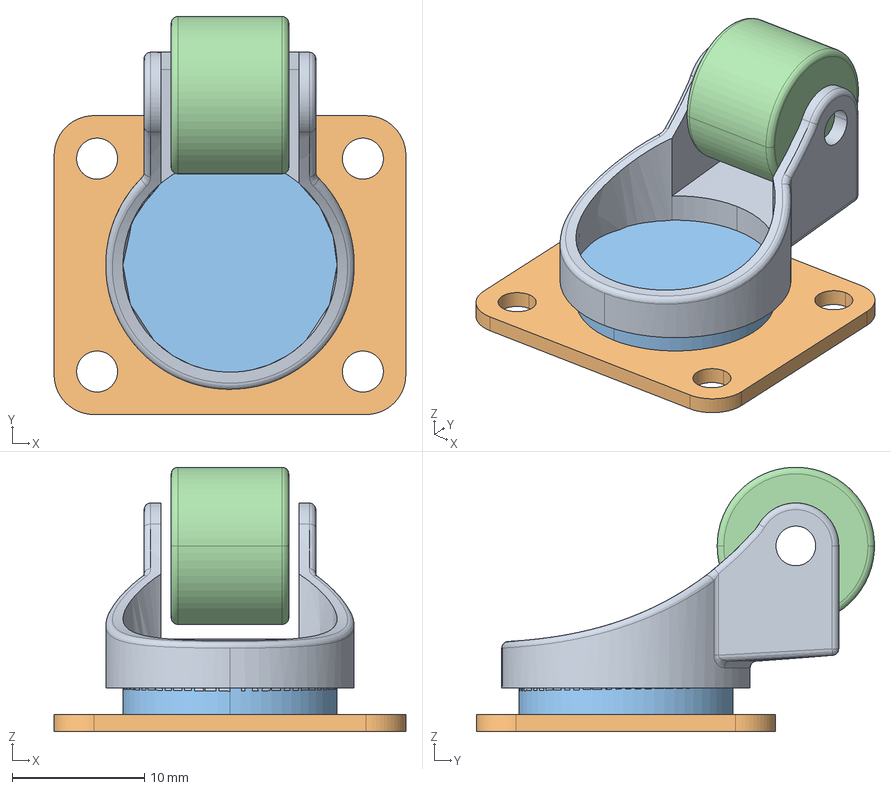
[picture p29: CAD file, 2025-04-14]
Main_Components'_FIiles/front-wheel.stp
26.6 x 30.1 x 20.0 mm

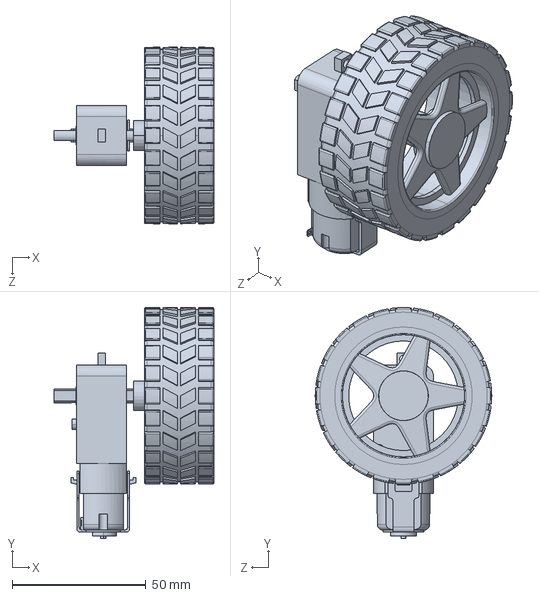
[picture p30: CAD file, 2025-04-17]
Main_Components/new-motor-2025.SLDPRT
59.7 x 86.4 x 66.0 mm

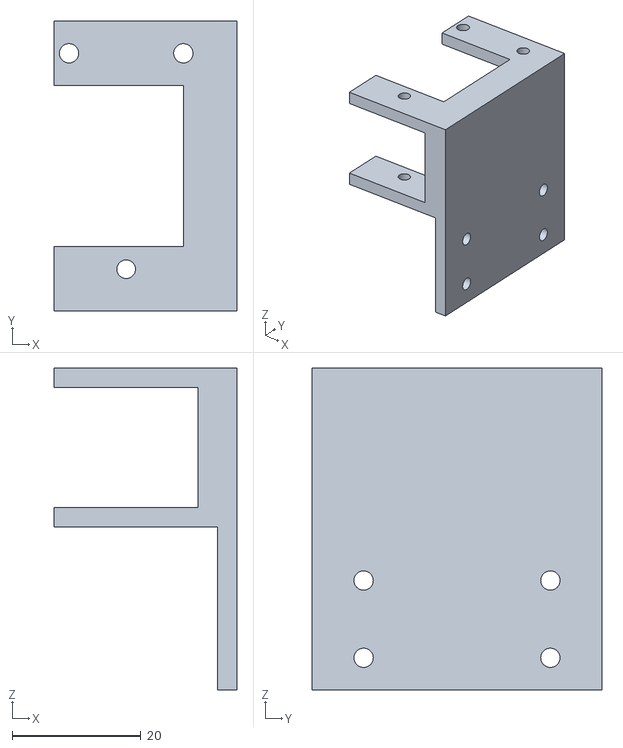
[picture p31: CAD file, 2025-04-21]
Milestone_1/Motor_Holder_Right_side_C1.STL
28.4 x 45.0 x 50.0

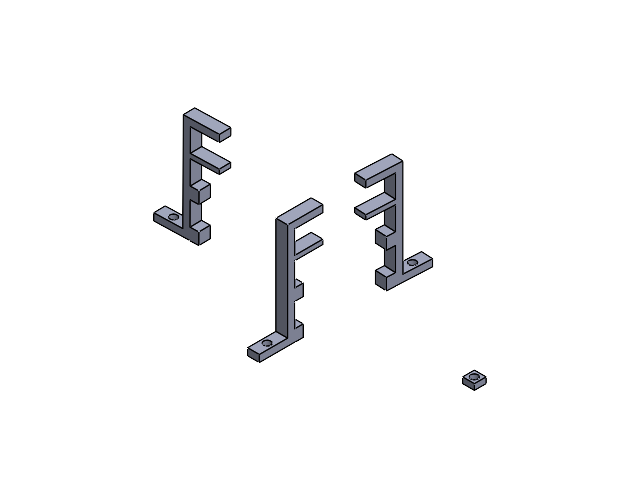
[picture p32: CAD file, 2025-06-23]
Ruhul_Updates/Battery and Breadboard Holder.SLDASM
BB_&_Battery_holder x 3
Small BB&B holder fron part

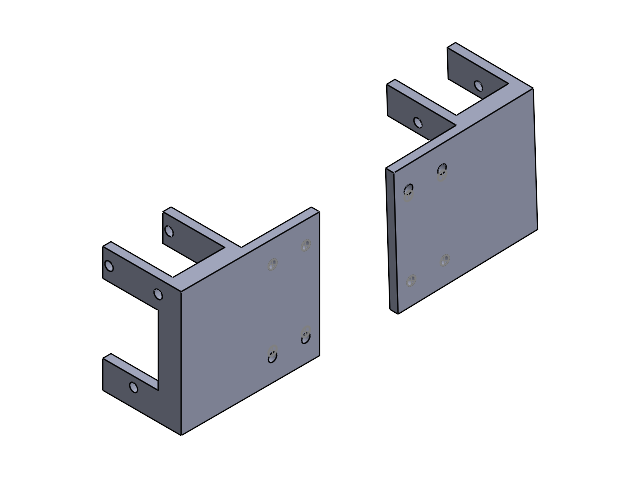
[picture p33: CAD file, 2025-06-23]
Ruhul_Updates/Motor Holders.SLDASM
Motor_Holder_Right_side x 2

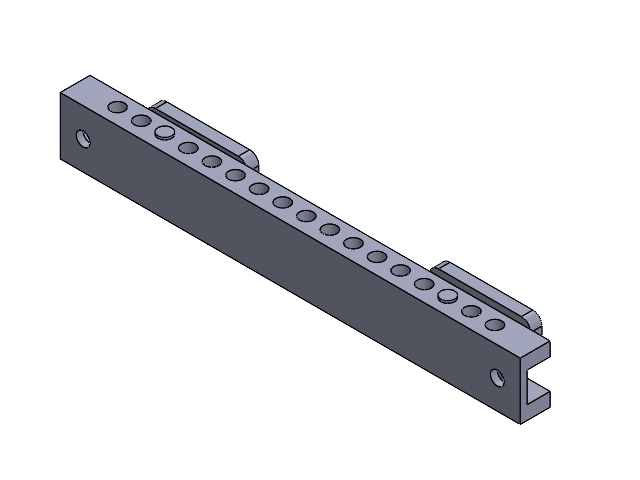
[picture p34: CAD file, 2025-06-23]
Ruhul_Updates/iR Holder New one.SLDASM
new_ir_2
New_IR holder x 2
NEW_IR_part3 x 2
stick x 2

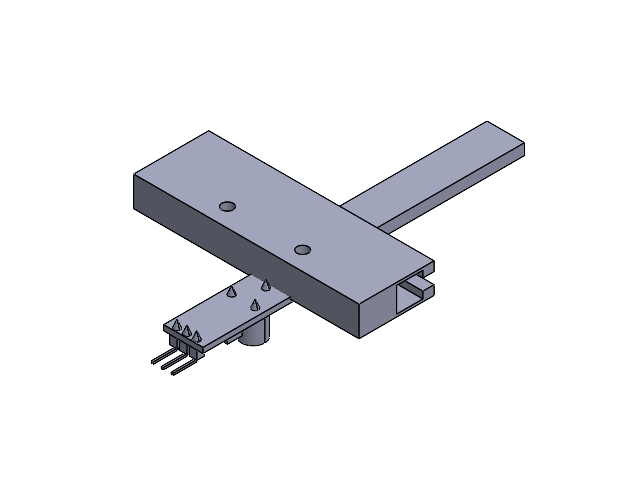
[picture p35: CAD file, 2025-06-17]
Ruhul_Updates/IR holder updated assembly.SLDASM
IR Holder new Update 1
IR Holder new update 2
infrared-sensor-new.step

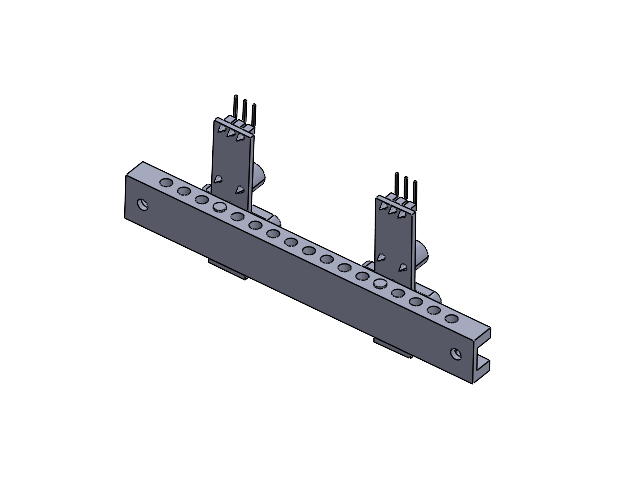
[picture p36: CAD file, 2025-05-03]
SolidWorks_Componets_by_Abdo/Assem_new ir.SLDASM
new_ir_2
infrared-sensor-new.step x 2
New_IR holder x 2
stick x 2
NEW_IR_part3 x 2

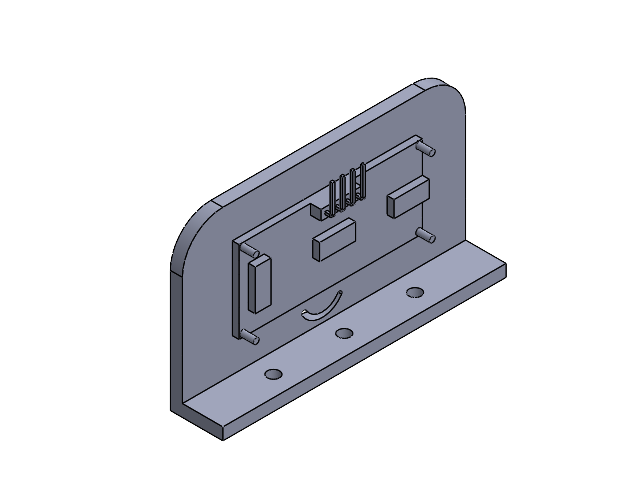
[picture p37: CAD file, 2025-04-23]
SolidWorks_Componets_by_Abdo/AssemUltrasonic-Holder.SLDASM
Ultrasonic_Holder
ultrasonic-sensor.step

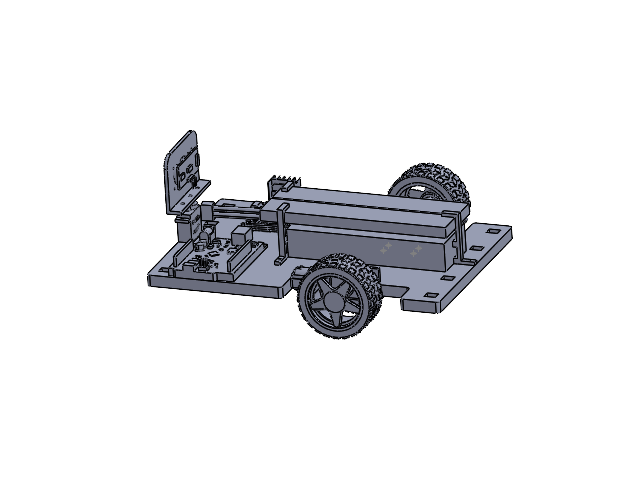
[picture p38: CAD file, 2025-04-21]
SolidWorks_Componets_by_Abdo/Assem_All.SLDASM
breadboard.stp
chassis.stp
Small BB&B holder fron part x 2
lipo-battery-updated
BB_&_Battery_holder x 3
stick x 6
front-wheel.stp
arduino.stp
new-motor-2025 x 2
Motor_Holder_Right_side
Motor_Holder_Left_side
infrared-sensor-new.step x 2
IR Holder Part1
IR Holder Part 2 x 2
Servo_Motor
Ultrasonic_Holder
ultrasonic-sensor.step
motorcontroler.step

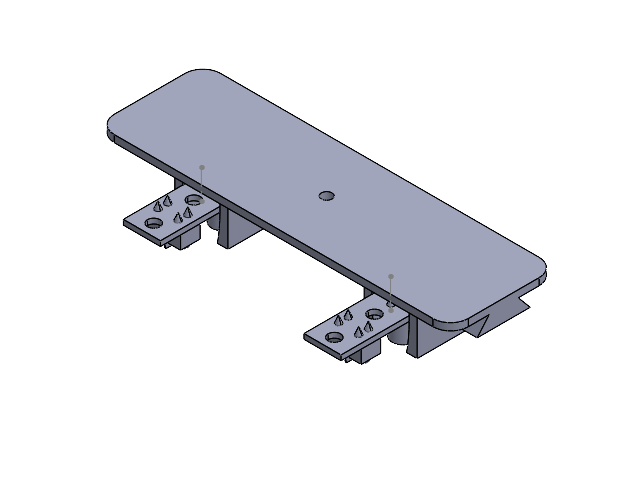
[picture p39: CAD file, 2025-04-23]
Ruhul_Updates/AssemIR update.SLDASM
IR Holder Updated Part 1
IR Holder Updated Part 2 x 2
infrared-sensor-new.step x 2

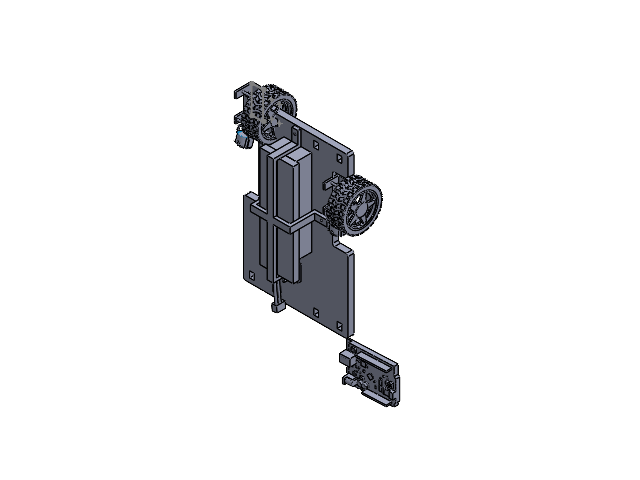
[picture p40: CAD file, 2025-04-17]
SolidWorks_Componets_by_Abdo/Assem2 side.SLDASM
chassis.stp
motor-with-tire.stp x 2
front-wheel.stp
Motor_Holder(Right side)
Motor_Holder(Left_side)
stick x 6
lipo-battery.stp
breadboard.stp
Battery_&_BB_Holder
arduino.stp

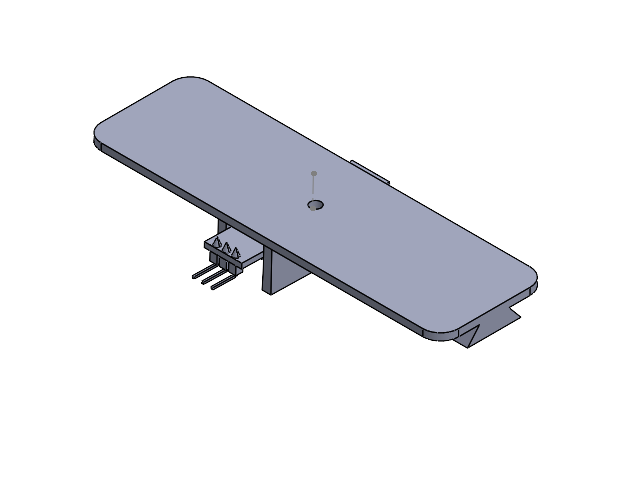
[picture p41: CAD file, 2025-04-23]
Ruhul_Updates/IR Holder Assembly.SLDASM
IR Holder Updated Part 1
IR Holder Updated Part 2
infrared-sensor-new.step

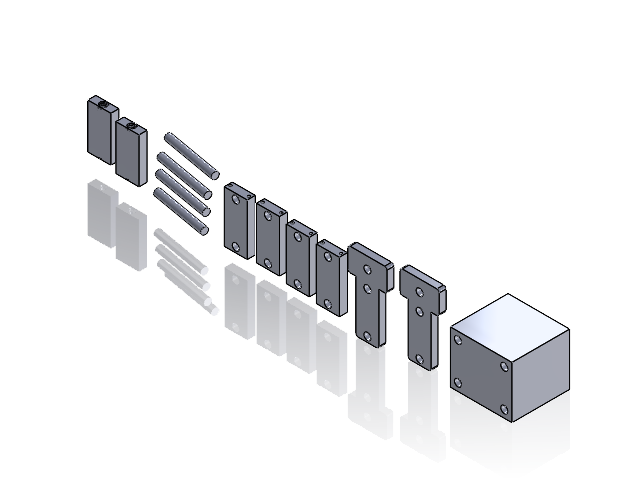
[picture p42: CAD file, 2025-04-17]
SolidWorks_Componets_by_Abdo/Component_For_Assem1.SLDASM
fron-Wheel_Support
Înternal_Motor-Holder x 4
stick x 4
External_Motor-Holder x 2
Servo-Holder x 2

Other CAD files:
Ruhul_Updates/Assem1.SLDASM
SolidWorks_Componets_by_Abdo/Assem1.SLDASM
Ruhul_Updates/Assem3.SLDASM
Ruhul_Updates/Motor Holder Final.SLDASM
Main_Components'_FIiles/arduino.stp
Main_Components'_FIiles/breadboard.stp
Main_Components'_FIiles/chassis.stp
Main_Components'_FIiles/infrared-sensor-new.STEP
Main_Components'_FIiles/infrared-sensor.STEP
Main_Components'_FIiles/motorcontroler.STEP
Main_Components'_FIiles/raspery-pi-pi-cam.STEP
Main_Components'_FIiles/ultrasonic-sensor.STEP
Main_Components/arduino.stp
Main_Components/breadboard.stp
Main_Components/chassis.stp
Main_Components/infrared-sensor-new.STEP
Main_Components/infrared-sensor.STEP
Main_Components/lipo-battery-updated.SLDPRT
Main_Components/motorcontroler.STEP
Main_Components/raspery-pi-pi-cam.STEP
Main_Components/ultrasonic-sensor.STEP
Milestone_1/All_Files_Together((PRINT_THIS_PLEASE))_C1.3mf
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

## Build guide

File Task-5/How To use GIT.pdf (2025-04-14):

How to use Git for (Robotic_Car_TeamC1-HSHL)

1- Download Git bash
2- Choose the Folder that you want to clone the Projcet in 3- Right Click then choose Open Git Bash Here
4- It will open you the git bash for that folder

5- Colne the Github Repositories with this command:

Git clone https://github.com/MoAbdoHSHL/Robotic_Car_TeamC1-HSHL.git
Now you can see the project in your folder

6- Run command in git to go inside the folder for changes:
cd Robotic_Car_TeamC1-HSHL

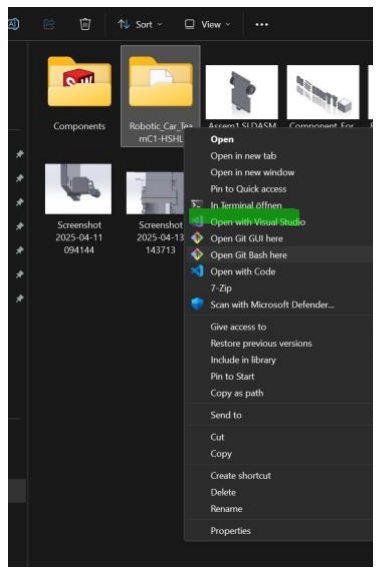
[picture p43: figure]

7- Run command: git add . (with the dott) to add all your changes into the phase for committing in git

8- Run command: git commit -m”Ex: Update in part_1 by Abdo” Now all your changes have been committed

9- If someone else made changes and you want to Upload these changes to your project folder
Run: git status # to see the changes in which files first
Then Run git push to push all these new Updates to your PC.

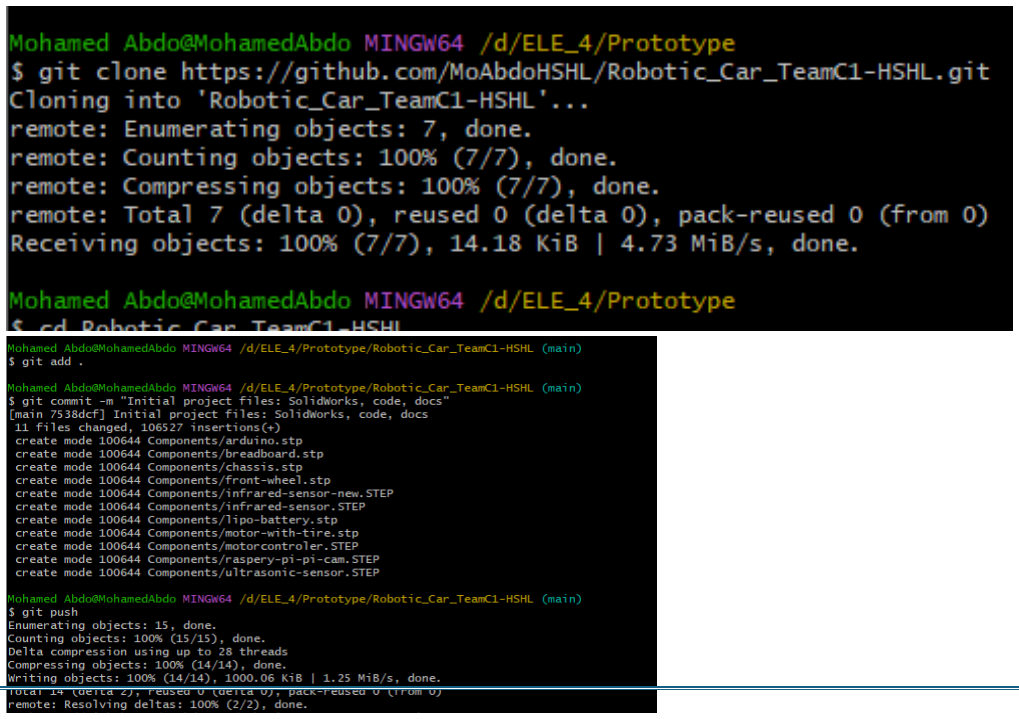
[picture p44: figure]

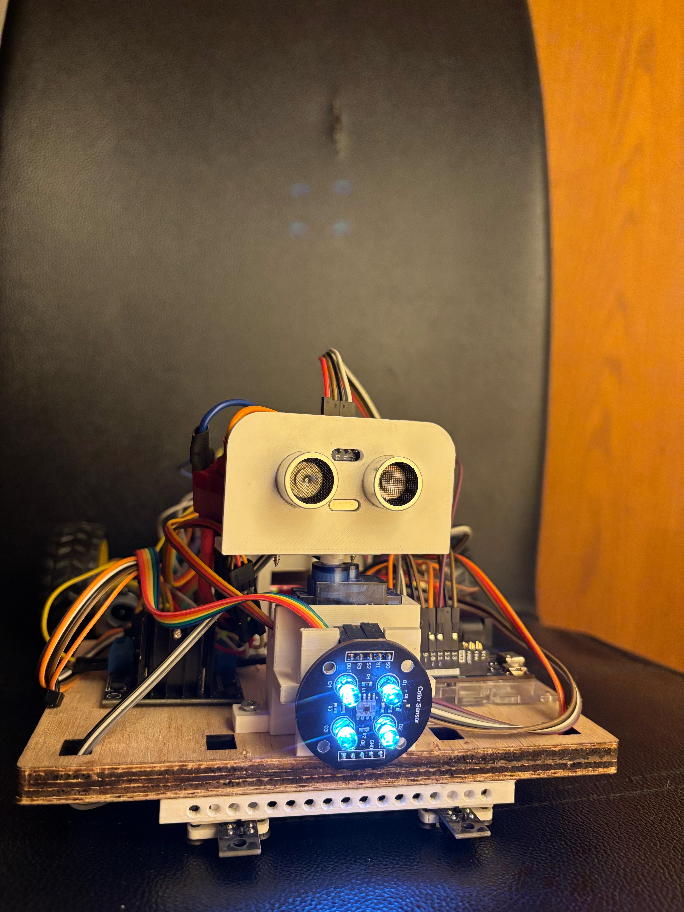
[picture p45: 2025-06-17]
Task-5/Prototype Connections and Soldering/Prototype Connections and Soldering 5.jpeg

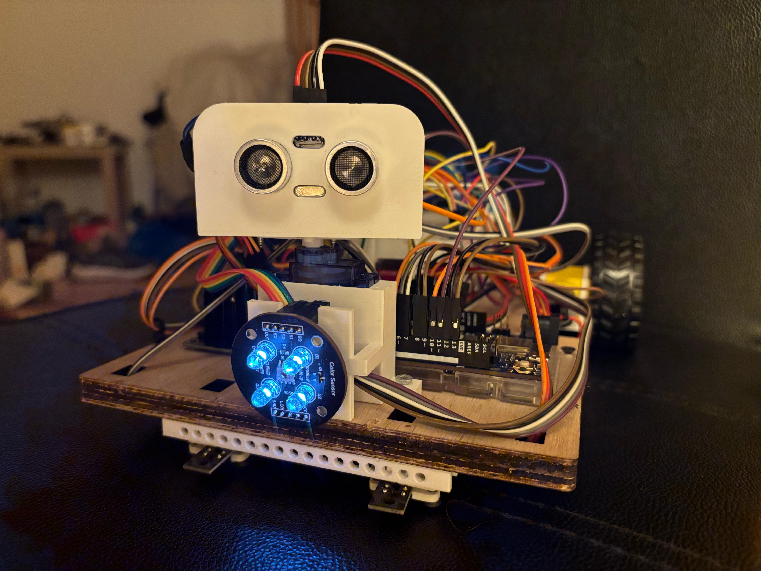
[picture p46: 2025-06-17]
Task-5/Prototype Connections and Soldering/Prototype Connections and Soldering 2.jpeg

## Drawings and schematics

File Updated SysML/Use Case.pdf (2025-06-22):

## Switch on/off

## Autonomous Path-Following and Obstacle Detection System

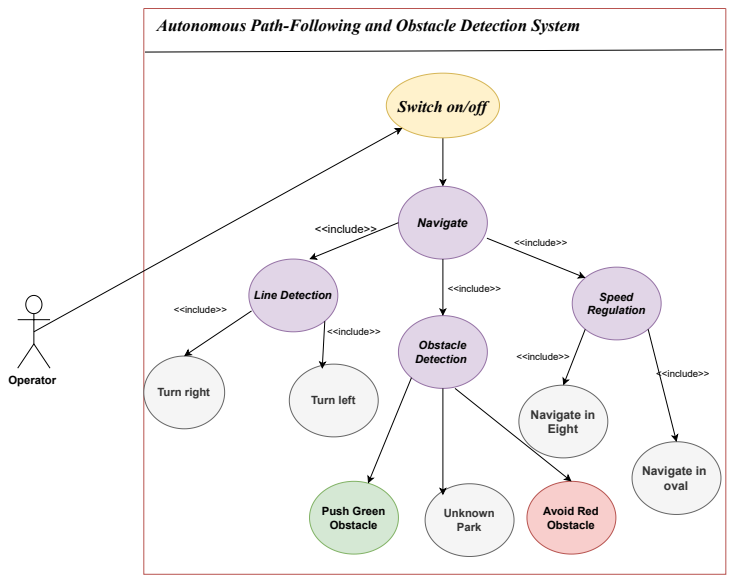
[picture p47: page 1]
Line Detection; Speed; Regulation; Turn right; Avoid Red Obstacle; Turn left; Navigate; Obstacle Detection; Navigate in Eight; Navigate in oval; <<include>>; Push Green Obstacle; Unknown Park; Operator

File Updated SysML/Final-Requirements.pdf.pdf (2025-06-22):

# <<Requirement>> Autonomous System Vehicle

### id=REQ=001

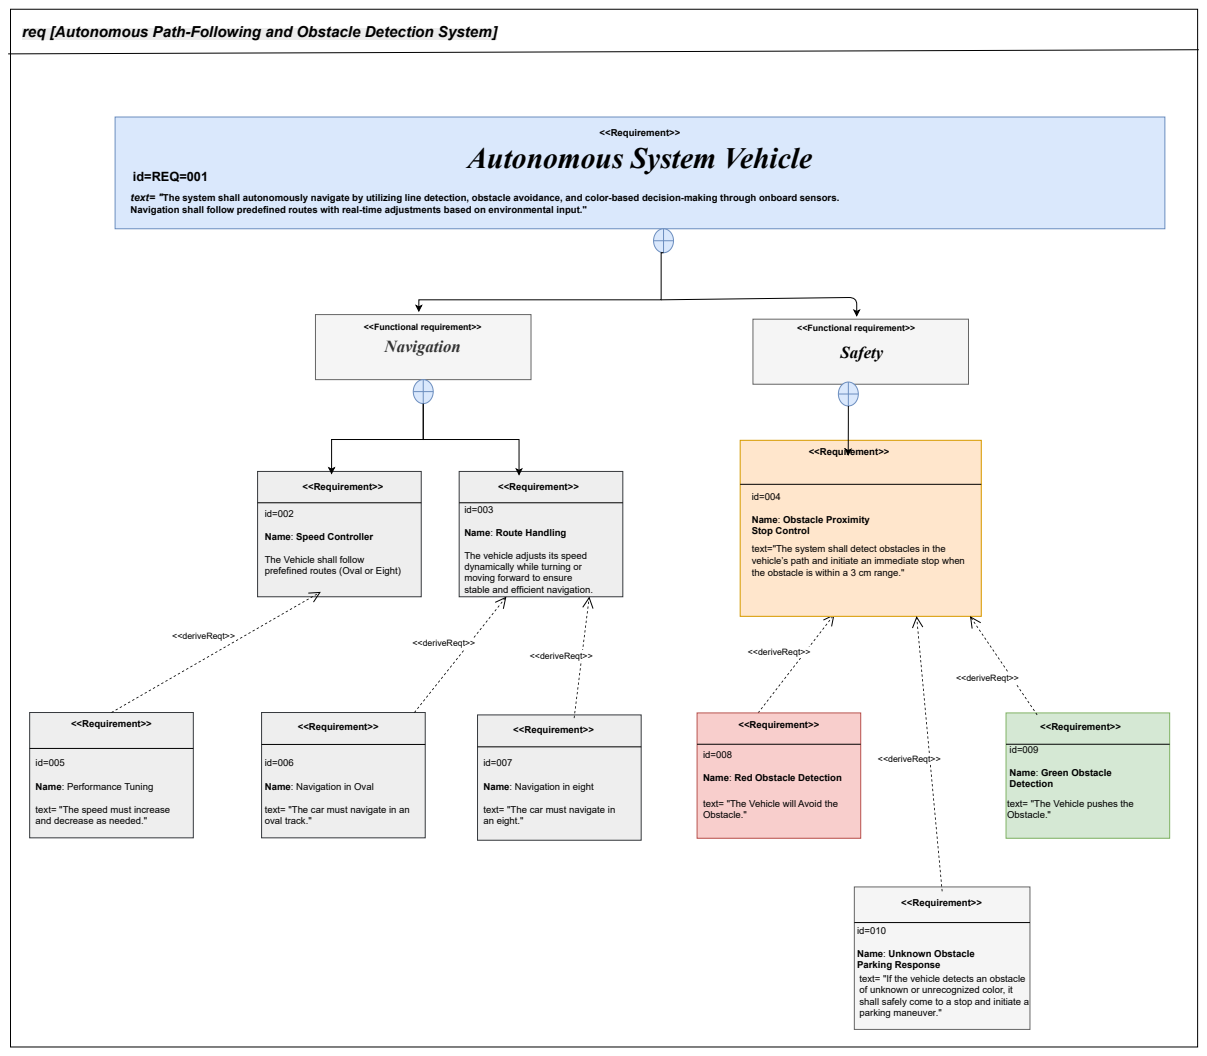
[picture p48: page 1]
Navigation; <<Requirement>>; <<deriveReqt>>; parking maneuver."; <<Functional requirement>>

req [Autonomous Path-Following and Obstacle Detection System]

text= "The system shall autonomously navigate by utilizing line detection, obstacle avoidance, and color-based decision-making through onboard sensors. Navigation shall follow predefined routes with real-time adjustments based on environmental input."

<<Functional requirement>> Safety

<<Requirement>> | <<Requirement>>

id=002 Name: Speed Controller The Vehicle shall follow prefefined routes (Oval or Eight) | id=003 Name: Route Handling The vehicle adjusts its speed dynamically while turning or moving forward to ensure stable and efficient navigation.

Name: Obstacle Proximity Stop Control

text="The system shall detect obstacles in the
vehicle’s path and initiate an immediate stop when
the obstacle is within a 3 cm range."

Name: Performance Tuning

Name: Navigation in Oval

Name: Navigation in eight

Name: Red Obstacle Detection

Name: Green Obstacle Detection

text= "The speed must increase
and decrease as needed."

text= "The car must navigate in an
oval track."

text= "The car must navigate in
an eight."

text= "The Vehicle will Avoid the Obstacle."

text= "The Vehicle pushes the Obstacle."

Name: Unknown Obstacle Parking Response

text= "If the vehicle detects an obstacle
of unknown or unrecognized color, it shall safely come to a stop and initiate a

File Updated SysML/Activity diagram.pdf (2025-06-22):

# AD [Autonomous Path-Following and Obstacle Detection System]

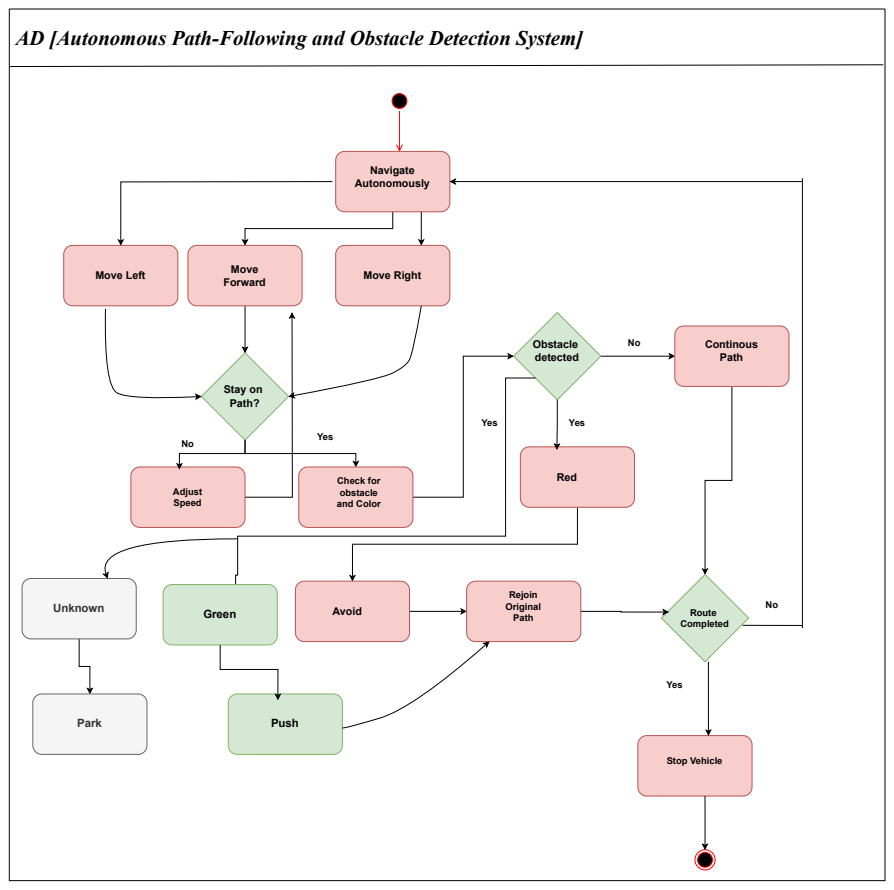
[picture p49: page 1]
Navigate Autonomously; Move Forward; Adjust Speed; and Color; Obstacle detected; Red; Avoid; Continous Path; Route Completed; Stop Vehicle; Yes; Move Left; Move Right; Push; Unknown; Green; Park

Stay on Path?

Yes Yes No

Check for obstacle

Rejoin Original Path

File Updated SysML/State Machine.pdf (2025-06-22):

## lDLE

## Navigating

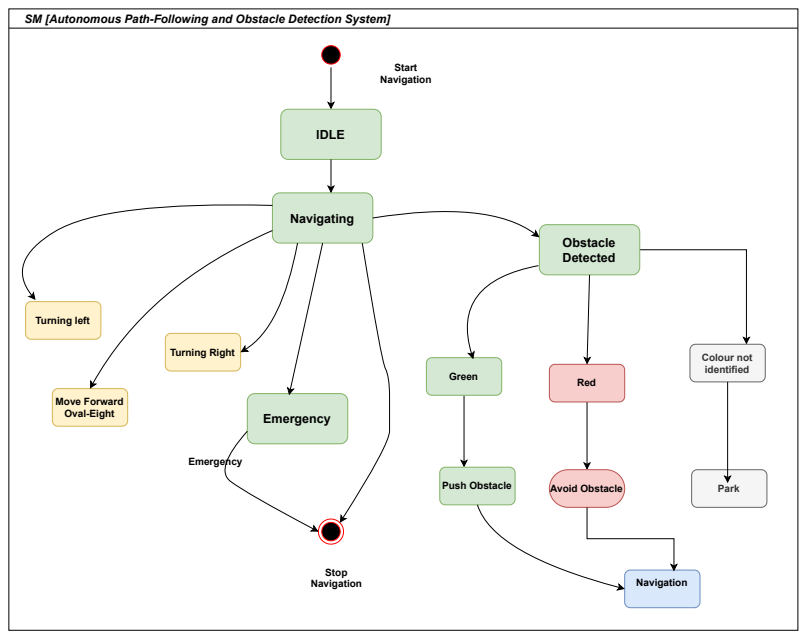
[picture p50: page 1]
Start Navigation; Emergency; Move Forward Oval-Eight; Turning Right; Turning left; Obstacle Detected; Red Green; Stop Navigation; Push Obstacle; Avoid Obstacle; Navigation; Colour not identified; Park

SM [Autonomous Path-Following and Obstacle Detection System]

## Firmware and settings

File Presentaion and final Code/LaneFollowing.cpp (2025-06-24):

#include <Servo.h>
#define enA 10
#define in1 9
#define in2 8
#define in3 7
#define in4 6
#define enB 5
#define L_S A4
#define R_S A5
#define trigPin 12
#define echoPin 13
#define servoPin 4
#define S0 A2
#define S1 A1
#define S2 2
#define S3 3
#define sensorOut A0
#define OE 11

float distance = 10;
bool avoidingObstacle = false;
unsigned long reengageStartTime = 0;
bool reengageInProgress = false;
int speedA = 58;
int speedB = 58;
Servo scanServo;
String detectedColor = "OTHER";
bool ultrasonicEnabled = true;
#define SERVO_CENTER 70
int turnSpeed = 60;
int curveDelay = 150;
int forwardSpeed = 70;


void readColor() {
  unsigned int red, green, blue;
  digitalWrite(S2, LOW); digitalWrite(S3, LOW); red = pulseIn(sensorOut, LOW);
  digitalWrite(S2, HIGH); digitalWrite(S3, HIGH); green = pulseIn(sensorOut, LOW);
  digitalWrite(S2, LOW); digitalWrite(S3, HIGH); blue = pulseIn(sensorOut, LOW);
  if (red < green && red < blue) detectedColor = "RED";
  else if (green < red && green < blue) detectedColor = "GREEN";
  else detectedColor = "OTHER";
  Serial.print("R="); Serial.print(red);
  Serial.print(" G="); Serial.print(green);
  Serial.print(" B="); Serial.println(blue);
  Serial.println("Detected Color: " + detectedColor);
}

void handleDetectedColor(String color) {
  int colorScenarioSpeed = 80;
  if (color == "RED") {
    delay(200);
    driveBackwards(12, colorScenarioSpeed);
    scanServo.write(180); delay(400);
    int leftDist = getDistance();
    scanServo.write(SERVO_CENTER); delay(200);
    if (leftDist > 20) {
      ultrasonicEnabled = false;
      rotate90(); delay(50);
      driveForward(20, colorScenarioSpeed); delay(200);
      rotateRight90(); delay(200);
      driveForward(20, colorScenarioSpeed);
      approachRightToLane();
      ultrasonicEnabled = true;
      Serial.println("RED: Path left is clear, performed left-right bypass.");
    } else {
      Serial.println("RED: Left not clear, only backed up and stopped.");
    }
    scanServo.write(SERVO_CENTER);
    stopMotors();
    Serial.println("RED scenario complete.");
  } else if (color == "GREEN") {
    delay(200);
    driveForward(20, 150);
    stopMotors(); delay(300);
    driveBackwards(40, 70);
    stopMotors(); delay(300);
    ultrasonicEnabled = false;
    unsigned long ignoreStart = millis();
    Serial.println("Ultrasonic disabled for 5 seconds...");
    while (millis() - ignoreStart < 5000) {
      int l = digitalRead(L_S);
      int r = digitalRead(R_S);
      if (l == 0 && r == 0) {
        analogWrite(enA, forwardSpeed);
        analogWrite(enB, forwardSpeed);
        forward();
      } else if (l == 1 && r == 0) {
        stopMotors(); delay(30);
        curveLeft();
      } else if (l == 0 && r == 1) {
        curveRight();
        stopMotors(); delay(30);
      } else {
        stopMotors();
        delay(100);
      }
      delay(20);
    }
    ultrasonicEnabled = true;
    Serial.println("Ultrasonic re-enabled, GREEN scenario complete: Lane reacquired.");
    stopMotors();
  } else {
    delay(200);
    driveBackwards(10, colorScenarioSpeed);
    delay(200);
    scanServo.write(0); delay(400);
    int rightDist = getDistance();
    scanServo.write(180); delay(400);
    int leftDist = getDistance();
    scanServo.write(SERVO_CENTER); delay(200);
    Serial.print("Scan distances: Right="); Serial.print(rightDist); Serial.print(", Left="); Serial.println(leftDist);
    if (rightDist > 40) {
      rotateRight90(); delay(200);
      stopMotors();
      Serial.println("Parked to the right.");
      while (1) { stopMotors(); }
    } else {
      Serial.println("Right not clear, not parking.");
    }
  }
}

void driveForward(int cm, int speed) {
  int t = cm * 30;
  analogWrite(enA, speed); analogWrite(enB, speed);
  digitalWrite(in1, HIGH); digitalWrite(in2, LOW);
  digitalWrite(in3, LOW); digitalWrite(in4, HIGH);
  delay(t);
  stopMotors(); delay(200);
}

void driveBackwards(int cm, int speed) {
  int t = cm * 30;
  analogWrite(enA, speed); analogWrite(enB, speed);
  digitalWrite(in1, LOW); digitalWrite(in2, HIGH);
  digitalWrite(in3, HIGH); digitalWrite(in4, LOW);
  delay(t);
  stopMotors(); delay(200);
}

void forward() {
  digitalWrite(in1, HIGH); digitalWrite(in2, LOW);
  digitalWrite(in3, LOW); digitalWrite(in4, HIGH);
}

void curveLeft() {
  analogWrite(enA, turnSpeed);
  analogWrite(enB, turnSpeed);
  digitalWrite(in1, LOW); digitalWrite(in2, HIGH);
  digitalWrite(in3, LOW); digitalWrite(in4, HIGH);
  delay(curveDelay);
  stopMotors();
}

void curveRight() {
  analogWrite(enA, turnSpeed);
  analogWrite(enB, turnSpeed);
  digitalWrite(in1, HIGH); digitalWrite(in2, LOW);
  digitalWrite(in3, HIGH); digitalWrite(in4, LOW);
  delay(curveDelay);
  stopMotors();
}

void rotate90() {
  int rotateSpeed = 100;
  analogWrite(enA, rotateSpeed); analogWrite(enB, rotateSpeed);
  digitalWrite(in1, LOW); digitalWrite(in2, HIGH);
  digitalWrite(in3, LOW); digitalWrite(in4, HIGH);
  delay(500);
  stopMotors(); delay(200);
}

void rotateRight90() {
  int rotateSpeed = 100;
  analogWrite(enA, rotateSpeed); analogWrite(enB, rotateSpeed);
  digitalWrite(in1, HIGH); digitalWrite(in2, LOW);
  digitalWrite(in3, HIGH); digitalWrite(in4, LOW);
  delay(500);
  stopMotors(); delay(200);
}

void approachRightToLane() {
  int l, r;
  int leftSpeed = 65;
  int rightSpeed = 40;
  while (true) {
    l = digitalRead(L_S);
    r = digitalRead(R_S);
    if (l == 1 || r == 1) {
      stopMotors();
      delay(100);
      Serial.println("ApproachRightToLane: Black detected, resuming normal lane following.");
      break;
    }
    analogWrite(enA, leftSpeed);
    analogWrite(enB, rightSpeed);
    digitalWrite(in1, HIGH); digitalWrite(in2, LOW);
    digitalWrite(in3, LOW);  digitalWrite(in4, HIGH);
    delay(120); stopMotors(); delay(5);
  }
  stopMotors();
}

int getDistance() {
  if (!ultrasonicEnabled) return 1000;
  digitalWrite(trigPin, LOW); delayMicroseconds(2);
  digitalWrite(trigPin, HIGH); delayMicroseconds(10);
  digitalWrite(trigPin, LOW);
  long duration = pulseIn(echoPin, HIGH, 20000);
  return duration * 0.034 / 2;
}

void stopMotors() {
  analogWrite(enA, 0);
  analogWrite(enB, 0);
  digitalWrite(in1, LOW); digitalWrite(in2, LOW);
  digitalWrite(in3, LOW); digitalWrite(in4, LOW);
}



void setup() {
  pinMode(enA, OUTPUT); pinMode(enB, OUTPUT);
  pinMode(in1, OUTPUT); pinMode(in2, OUTPUT); pinMode(in3, OUTPUT); pinMode(in4, OUTPUT);
  pinMode(L_S, INPUT); pinMode(R_S, INPUT);
  pinMode(trigPin, OUTPUT); pinMode(echoPin, INPUT);
  pinMode(S0, OUTPUT); pinMode(S1, OUTPUT); pinMode(S2, OUTPUT); pinMode(S3, OUTPUT);
  pinMode(OE, OUTPUT); pinMode(sensorOut, INPUT);
  digitalWrite(OE, LOW);
  digitalWrite(S0, HIGH);
  digitalWrite(S1, LOW);
  scanServo.attach(servoPin);
  scanServo.write(SERVO_CENTER);
  Serial.begin(9600);
  Serial.println("Robot with Color Detection Started");
}

void loop() {
  distance = getDistance();
  if (distance > 0 && distance <= 6) {
    stopMotors();
    delay(500);
    readColor();
    handleDetectedColor(detectedColor);
    delay(500);
    return;
  }
  int left = digitalRead(L_S);
  int right = digitalRead(R_S);
  Serial.print("Left IR: "); Serial.print(left);
  Serial.print(" | Right IR: "); Serial.println(right);
  if (left == 0 && right == 0) {
    moveForward(speedA, speedB);
  }
  else if (left == 0 && right == 1) {
    leftForward(80);
    rightBackward(67);
    
  }
  else if (left == 1 && right == 0) {
    leftBackward(67);
    rightForward(80);
    
  }
  else {
    stopMotors();
  }
}


void moveForward(int speedVal1, int speedVal2) {
  analogWrite(enA, speedVal1);
  analogWrite(enB, speedVal2);
  digitalWrite(in1, HIGH);
  digitalWrite(in2, LOW);
  digitalWrite(in3, LOW);
  digitalWrite(in4, HIGH);
}

void moveBackward(int speedVal1, int speedVal2) {
  analogWrite(enA, speedVal1);
  analogWrite(enB, speedVal2);
  digitalWrite(in1, LOW);
  digitalWrite(in2, HIGH);
  digitalWrite(in3, HIGH);
  digitalWrite(in4, LOW);
}

void leftForward(int speedVal) {
  analogWrite(enA, speedVal);
  digitalWrite(in1, HIGH);
  digitalWrite(in2, LOW);
}

void leftBackward(int speedVal) {
  analogWrite(enA, speedVal);
  digitalWrite(in1, LOW);
  digitalWrite(in2, HIGH);
}

void rightForward(int speedVal) {
  analogWrite(enB, speedVal);
  digitalWrite(in3, LOW);
  digitalWrite(in4, HIGH);
}

void rightBackward(int speedVal) {
  analogWrite(enB, speedVal);
  digitalWrite(in3, HIGH);
  digitalWrite(in4, LOW);
}

void moveForward1(int speedVal) {
  analogWrite(enA, speedVal);
  analogWrite(enB, speedVal);
  digitalWrite(in1, HIGH);
  digitalWrite(in2, LOW);
  digitalWrite(in3, LOW);
  digitalWrite(in4, HIGH);
}

void handleObstacle() {
  stopMotors(); delay(300);
  moveBackward(80, 80); delay(500); stopMotors(); delay(300);
  leftBackward(180); rightForward(180); delay(180); stopMotors(); delay(300);
  moveForward(65, 65); delay(1600); stopMotors(); delay(300);
  leftForward(200); rightBackward(200); delay(280); stopMotors(); delay(300);
  moveForward1(80); delay(300);
  waitForLineDetection();
  avoidingObstacle = false;
}

void waitForLineDetection() {
  Serial.println("Searching for line...");
  while (true) {
    int l = digitalRead(L_S);
    int r = digitalRead(R_S);
    if (l == 1 || r == 1) {
      Serial.println("Line detected!");
      break;
    } else {
      moveForward1(50);
    }
    delay(10);
  }
}

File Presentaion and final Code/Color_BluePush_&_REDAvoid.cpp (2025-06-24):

// ------------------------------------------------------
// Line Following Robot with Color Obstacle Scenarios
//
// Copy Right for Group (C1) HSHL
//
// Members:
// - Mohamed Abdo
// - Md Ruhul Kuddus Saleh
// - Md Rahman
// - Aamir Ejaz
//
// Project Overview:
// This Arduino code controls a line-following robot that can detect colored obstacles
// and react differently to each color:
//
// </> RED Obstacle </>:
//    The robot backs up, checks if the left side is clear, and if so, bypasses the obstacle by going around it,
//    then returns to the lane and continues.
// </> BLUE Obstacle (FLIPPED with GREEN) </>:
//    The robot moves forward to push the obstacle, then reverses back on the lane. After that, the ultrasonic
//    sensor is disabled for 5 seconds to avoid detecting the same obstacle again.
// </> GREEN or OTHER Colors (FLIPPED with BLUE) </>:
//    The robot backs up, scans left and right, and if the right side is clear, parks to the right and stops.
//
// The robot follows a black line using infrared sensors, uses an ultrasonic sensor to detect obstacles ahead,
// and a color sensor to recognize the obstacle color and trigger the correct scenario.
//

#include <Servo.h>
#define enA 10
#define in1 9
#define in2 8
#define in3 7
#define in4 6
#define enB 5
#define L_S A4
#define R_S A5
#define trigPin 12
#define echoPin 13
#define S0 A2
#define S1 A1
#define S2 2
#define S3 3
#define colorOut A0
#define servoPin 4
#define SERVO_CENTER 70

Servo scanServo;

int forwardSpeed = 65;
int turnSpeed = 80;
int curveDelay = 150;
int approachThreshold = 20;
int scanThreshold = 2.8;
int approachSpeed = 80;
bool ultrasonicEnabled = true;
bool approaching = false;
String detectedColor = "UNKNOWN";

void forward();
void backward();
void turnLeft();
void turnRight();
void Stop();
void curveLeft();
void curveRight();
void approachToObstacle();
void readColor();
void handleDetectedColor(String color);
void driveForward(int cm, int speed = 70);
void driveBackwards(int cm, int speed = 70);
void rotate90();
void rotateRight90();
void approachRightToLane();
int getDistance();

void setup() {
  Serial.begin(9600);
  pinMode(R_S, INPUT); pinMode(L_S, INPUT);
  pinMode(enA, OUTPUT); pinMode(enB, OUTPUT);
  pinMode(in1, OUTPUT); pinMode(in2, OUTPUT);
  pinMode(in3, OUTPUT); pinMode(in4, OUTPUT);
  pinMode(trigPin, OUTPUT); pinMode(echoPin, INPUT);
  pinMode(S0, OUTPUT); pinMode(S1, OUTPUT);
  pinMode(S2, OUTPUT); pinMode(S3, OUTPUT);
  pinMode(colorOut, INPUT);
  digitalWrite(S0, HIGH); digitalWrite(S1, LOW);
  scanServo.attach(servoPin);
  scanServo.write(SERVO_CENTER);
  delay(300);
}

void loop() {
  int leftIR = digitalRead(L_S);
  int rightIR = digitalRead(R_S);
  int distance = getDistance();

  Serial.print("L_IR="); Serial.print(leftIR);
  Serial.print(" | R_IR="); Serial.print(rightIR);
  Serial.print(" | Distance="); Serial.println(distance);

  if (!approaching && distance > 0 && distance <= approachThreshold && leftIR == 0 && rightIR == 0) {
    approaching = true;
    Serial.println("Obstacle detected at " + String(distance) + "cm");
    Stop(); delay(300);
  }

  if (approaching) {
    approachToObstacle();
    return;
  }

  if (distance > 0 && distance <= approachThreshold) {
    Stop();
    Serial.println("Obstacle ahead! Stopping.");
    delay(500);
    return;
  }

  if (leftIR == 0 && rightIR == 0) {
    analogWrite(enA, forwardSpeed);
    analogWrite(enB, forwardSpeed);
    forward();
  } else if (leftIR == 1 && rightIR == 0) {
    Stop(); delay(30);
    curveLeft();
  } else if (leftIR == 0 && rightIR == 1) {
    curveRight();
    Stop(); delay(30);
  } else {
    Stop();
    delay(100);
  }
}

void approachToObstacle() {
  int l, r, d;
  unsigned long stepTime = 30;
  while (true) {
    d = getDistance();
    l = digitalRead(L_S); r = digitalRead(R_S);
    if (l == 1 && r == 1) {
      Serial.println("Lost line during approach! Aborting.");
      Stop(); delay(300); ultrasonicEnabled = true; approaching = false; return;
    }
    if (d <= scanThreshold || d <= 0) break;
    if (l == 0 && r == 0) {
      analogWrite(enA, approachSpeed); analogWrite(enB, approachSpeed);
      forward(); delay(stepTime); Stop();
    } else if (l == 1 && r == 0) {
      analogWrite(enA, 0); analogWrite(enB, approachSpeed);
      digitalWrite(in1, LOW); digitalWrite(in2, LOW);
      digitalWrite(in3, LOW); digitalWrite(in4, HIGH);
      delay(stepTime); Stop();
    } else if (l == 0 && r == 1) {
      analogWrite(enA, approachSpeed); analogWrite(enB, 0);
      digitalWrite(in1, HIGH); digitalWrite(in2, LOW);
      digitalWrite(in3, LOW); digitalWrite(in4, LOW);
      delay(stepTime); Stop();
    }
    delay(10);
  }
  Stop(); delay(300); readColor(); handleDetectedColor(detectedColor);
  delay(500); approaching = false;
}

void readColor() {
  unsigned int red, green, blue;
  digitalWrite(S2, LOW); digitalWrite(S3, LOW); red = pulseIn(colorOut, LOW);
  digitalWrite(S2, HIGH); digitalWrite(S3, HIGH); green = pulseIn(colorOut, LOW);
  digitalWrite(S2, LOW); digitalWrite(S3, HIGH); blue = pulseIn(colorOut, LOW);
  
  if (red < green && red < blue) detectedColor = "RED";
  else if (blue < red && blue < green) detectedColor = "BLUE";
  else if (green < red && green < blue) detectedColor = "GREEN";
  else detectedColor = "OTHER";
  Serial.print("R="); Serial.print(red);
  Serial.print(" G="); Serial.print(green);
  Serial.print(" B="); Serial.println(blue);
  Serial.println("Detected Color: " + detectedColor);
}
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

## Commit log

2025-04-14 Initial project files: SolidWorks, code, docs
    [arduino.stp, breadboard.stp, chassis.stp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]
2025-04-14 Update by Abdo in file 1
    [arduino.stp, breadboard.stp, chassis.stp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]
2025-04-14 Update assm file by abdo
    [Assem1.SLDASM, Component_For_Assem1.SLDASM]
2025-04-14 Upload Tasx xlsx by Abdo
    [Team_Tasks.xlsx]
2025-04-16 Ultrasonic Holder by Ruhul
    [Ultrasonic_Holder.SLDPRT]
2025-04-17 Motor holder by Abdo
    [Assem Lipo &BB Holder.SLDASM, Assem1.SLDASM, Assem2 side.SLDASM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]
2025-04-17 Create IR Holder.SLDPRT
    [IR Holder.SLDPRT]
2025-04-17 IR Holder updates by Ruhul
    [Assem1.SLDASM, IR Holder Part 2.SLDPRT, IR Holder Part1.SLDPRT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]
2025-04-18 IR Holders updates by Ruhul
    [IR Holder Part 2.STL, IR Holder Part1.STL]
2025-04-21 Colour sensor holder by ruhul
    [Color sensor holder.SLDPRT, IR Holder Part 2.SLDPRT]
2025-04-21 colour sensor
2025-04-23 IR Holder updated by Ruhul
    [Assem1.SLDASM, IR Holder Assembly.SLDASM, IR Holder Updated Part 1.SLDPRT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]
2025-05-02 ir holder new updated by ruhul
    [Color sensor and servo holder updated.SLDPRT, IR Holder new Update 1.SLDPRT, IR Holder new Update 1.STL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]
2025-05-04 Included Servo Motor
2025-06-01 Update Color-Servo-Ultra-IR.ino _by Abdo
2025-06-08 Create Battery Voltage and System Optimization with PID Control.cpp
2025-06-15 Prototype Team C1 Task Updates
    [Team_Tasks.xlsx]
2025-06-23 Pictures and videos
    [Battery and Breadboard Holder.SLDASM, Motor Holders.SLDASM, iR Holder New one.SLDASM]
2025-06-24 Create color BLUE push && RED avoid.cpp
    [color BLUE push && RED avoid.cpp]
2025-07-03 Create Implementing switch-case and millis.cpp
